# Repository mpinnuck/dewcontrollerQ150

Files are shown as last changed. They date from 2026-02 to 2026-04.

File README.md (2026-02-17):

# Q150 Dew Controller

An intelligent dew prevention system for astronomical telescopes and optical equipment, featuring automatic humidity monitoring and adaptive heating control.

## Overview

The Q150 Dew Controller uses precise temperature and humidity sensing to calculate dew point and automatically control heater power to prevent condensation on telescope optics. The system features both WiFi web interface and Bluetooth Low Energy (BLE) connectivity for remote monitoring and configuration.

## Key Features

### Environmental Monitoring
- **SHT45 Sensor**: High-precision temperature (±0.1°C) and humidity (±1.5% RH) measurement
- **Real-time Dew Point Calculation**: Continuous monitoring of dew point temperature
- **Spread Tracking**: Calculates temperature margin above dew point

### Intelligent Heating Control
- **Adaptive Power Control**: Automatically adjusts heater power based on dew point spread
- **Configurable Power Table**: Up to 5 spread→power mapping points for custom response curves
- **Manual Override**: Direct power control via slider (0-100%)
- **PWM Output**: Smooth, efficient heater control on D8 pin

### Connectivity

#### WiFi Web Interface
- **Responsive Design**: Works on desktop, tablet, and mobile devices
- **Real-time Updates**: Live sensor readings every 2 seconds
- **Configuration**: WiFi credentials, timezone, and heater settings
- **Fast Disconnect Detection**: 1-second timeout for quick offline status
- **Automatic Reconnection**: Seamless recovery when connection is restored

#### Bluetooth Low Energy (BLE)
- **Desktop Management App**: Python-based configuration tool
- **Auto-connect**: Automatically finds and connects to Q150 devices
- **Config Management**: Read/write heater settings and spread table
- **Cross-platform**: macOS, Windows, Linux support

### Time & Logging
- **NTP Time Sync**: Automatic time synchronization via internet
- **Timezone Support**: 18 worldwide timezones with automatic DST adjustment
- **POSIX Timezones**: Full support for complex timezone rules
- **Timestamped Logs**: Real date/time stamps when NTP synced, boot time otherwise

### Network Modes
- **Station Mode**: Connects to existing WiFi network
- **Fallback AP Mode**: Creates "Q150Dew" access point if connection fails
- **mDNS**: Access via `q150dew.local` hostname
- **Persistent Settings**: WiFi credentials stored in flash

## Hardware

### Microcontroller
- **Board**: Seeed Studio XIAO ESP32-S3
- **CPU**: Dual-core Xtensa 32-bit LX7 @ 240MHz
- **Memory**: 512KB SRAM, 8MB Flash
- **Connectivity**: WiFi 802.11 b/g/n, BLE 5.0

### Sensor
- **Model**: Sensirion SHT45
- **Interface**: I2C (SDA=D4, SCL=D5)
- **Accuracy**: ±0.1°C, ±1.5% RH
- **Range**: -40°C to 125°C, 0-100% RH

### Output
- **PWM Pin**: D8 (Pin 9)
- **Frequency**: 1 kHz
- **Resolution**: 8-bit (0-255)
- **Driver**: External MOSFET (FQP30N06) for high-current loads

### PCB
- Custom KiCAD design in `hardware/dewcontrollerQ150/`
- Gerber files ready for fabrication in `hardware/dewcontrollerQ150/pcbfiles/`

### Enclosure
- FreeCAD design in `housing/Q150DewController.FCStd`
- STL files for 3D printing in `housing/stl/`

## Firmware

**Version**: 2.1  
**File**: `firmware/dewcontrollerq150/dewcontrollerq150.ino`

### Dependencies
Install via Arduino Library Manager:
- ArduinoJson (6.x)
- Adafruit SHT4x Library
- ESP32 BLE Arduino

### Compilation
1. Install [Arduino IDE](https://www.arduino.cc/en/software) or [PlatformIO](https://platformio.org/)
2. Install ESP32 board support: https://docs.espressif.com/projects/arduino-esp32/
3. Select board: **XIAO_ESP32S3**
4. Open `firmware/dewcontrollerq150/dewcontrollerq150.ino`
5. Set `DEBUG` to `0` for release build (line 16)
6. Compile and upload

### Configuration
Default WiFi fallback credentials:
- **SSID**: `Q150Dew`
- **Password**: `tinka`

Default timezone: Australia (Sydney/Melbourne) with automatic DST

## Desktop Application

**File**: `app/q150dewcontroller.py`

### Features
- Auto-discovery and connection to Q150 devices
- Read device info and current configuration
- Edit and update:
  - Heater enable/disable
  - Spread→Power table (5 entries)
  - WiFi SSID and password
  - Timezone selection
- Real-time status monitoring
- Cross-platform (macOS, Windows, Linux)

### Requirements
```bash
pip install bleak
```

### Running
```bash
cd app
python q150dewcontroller.py
```

### Building Executable
```bash
cd app
pyinstaller q150dewcontroller.spec --noconfirm
```

Built app will be in `app/dist/q150dewcontroller.app` (macOS) or `app/dist/q150dewcontroller.exe` (Windows)

## Usage

### Initial Setup
1. Power on the Q150 Dew Controller
2. Connect to WiFi AP "Q150Dew" (password: "tinka")
3. Open browser to `http://192.168.4.1` or `http://q150dew.local`
4. Configure your WiFi credentials and timezone
5. Device will restart and connect to your network

### Web Interface
Access via `http://q150dew.local` or device IP address

**Main Panel**:
- Temperature, humidity, dew point, and spread readings
- Heater status (ON/OFF) and current power level
- WiFi connection status and signal strength
- Current time (when NTP synced)

**Control Panel**:
- **Toggle Heater**: Enable/disable automatic control
- **Manual Power Slider**: Override automatic control (0-100%)
- **Spread Table**: Configure up to 5 spread→power points
- **WiFi Config**: Update credentials and timezone

**System Log**:
- Real-time event log with timestamps
- Pause/resume log updates
- Connection status, sensor readings, configuration changes

### BLE Management App
1. Launch `q150dewcontroller` application
2. Click **Scan & Connect** to find devices
3. Device info and status display automatically
4. Edit configuration settings as needed
5. Click **Write Config** to save changes to device

### Power Table Configuration
Define the relationship between temperature spread (T - Tdew) and heater power:

Example table:
| Spread (°C) | Power (%) |
|---|---|
| 0.0 | 100 |
| 2.0 | 75 |
| 5.0 | 50 |
| 10.0 | 25 |
| 15.0 | 0 |

The controller interpolates between points for smooth power transitions.

## Technical Details

### API Endpoints

**GET /api/status**
Returns current sensor readings, heater status, WiFi info, and time

**POST /api/toggle**
Toggles heater enabled state

**POST /api/power**
Sets manual power override (0-100)

**POST /api/config**
Updates heater configuration and spread table

**POST /api/wifi**
Updates WiFi credentials and timezone (triggers restart)

**GET /api/log**
Returns system event log

### BLE Characteristics

**Service UUID**: `12345678-1234-1234-1234-123456789abc`

- **INFO**: Device information (read-only)
- **STATUS**: Real-time sensor data (read/notify)
- **CONFIG**: Configuration settings (read/write)
- **CMD**: Command interface (write)

### Dew Point Calculation
Uses Magnus formula:
```
γ(T,RH) = ln(RH/100) + (b×T)/(c+T)
Tdew = (c×γ)/(b-γ)
```
Where: b = 17.62, c = 243.12°C

### Timezone Support
18 timezones with POSIX format including:
- UTC, UK (GMT/BST)
- Europe (CET, EET)
- US (EST, CST, MST, PST, AKST, HST)
- Australia (AEST, ACST, AWST)
- New Zealand, Japan, China, India, Middle East

Automatic daylight saving time adjustments.

## Development

### Repository Structure
```
dewcontrollerQ150/
├── firmware/
│   └── dewcontrollerq150/
│       └── dewcontrollerq150.ino    # ESP32 firmware
├── app/
│   ├── q150dewcontroller.py         # Python BLE app
│   └── q150dewcontroller.spec       # PyInstaller spec
├── hardware/
│   └── dewcontrollerQ150/
│       ├── dewcontrollerQ150.kicad_pcb   # PCB design
│       ├── dewcontrollerQ150.kicad_sch   # Schematic
│       └── pcbfiles/                     # Gerber files
└── housing/
    ├── Q150DewController.FCStd      # FreeCAD model
    └── stl/                         # 3D print files
```

### Version History
- **v2.1**: Debounced slider, improved disconnect detection, timezone config in BLE app
- **v2.0**: WiFi configuration, NTP time sync, responsive mobile UI
- **v1.3**: Enhanced BLE, power table configuration
- **v1.2**: PCB revision, housing design
- **v1.0**: Initial production version

## Troubleshooting

**Device won't connect to WiFi**
- Check SSID and password in WiFi Config
- Ensure 2.4GHz WiFi (5GHz not supported)
- Device will fall back to AP mode "Q150Dew" if connection fails

**Web interface shows "Disconnected"**
- Check device is powered on
- Verify you're on the same network
- Try accessing by IP address instead of hostname

**NTP time not syncing**
- Requires internet connection
- Check timezone setting is correct
- Time will show "Not synced" until successful NTP update

**Heater not responding**
- Check heater is enabled (not just power set)
- Verify MOSFET and heater connections
- Check spread table has valid entries

## License

Copyright © 2026 Mark Pinnuck

## Acknowledgments

- Sensirion for SHT45 sensor library
- Seeed Studio for XIAO ESP32-S3 platform
- Arduino and ESP32 communities

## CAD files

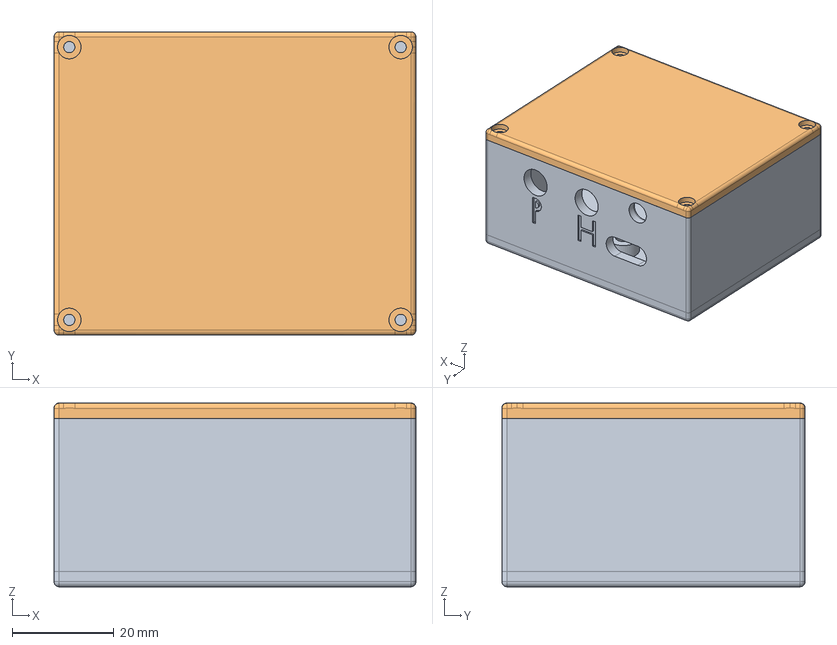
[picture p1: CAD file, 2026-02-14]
housing/Q150DewController.FCStd
71.0 x 59.5 x 36.0 mm
Base
Lid

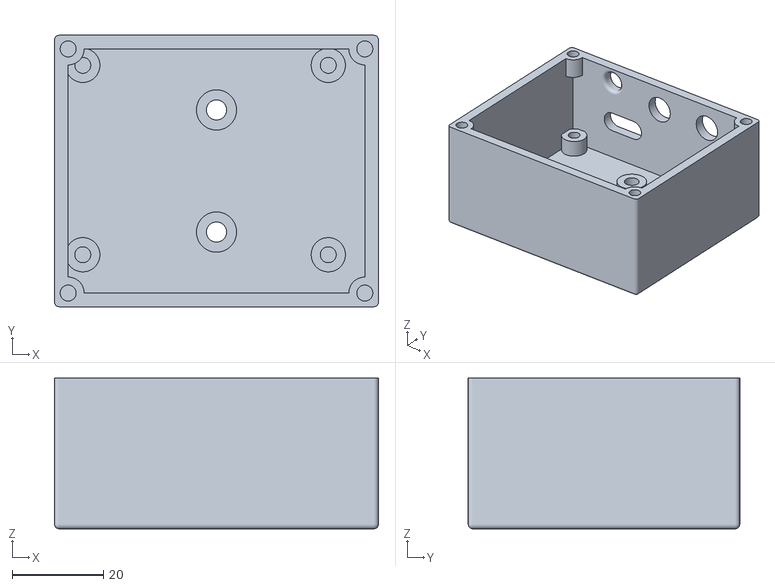
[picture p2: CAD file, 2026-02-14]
housing/stl/Base.stl
71.0 x 59.5 x 33.0

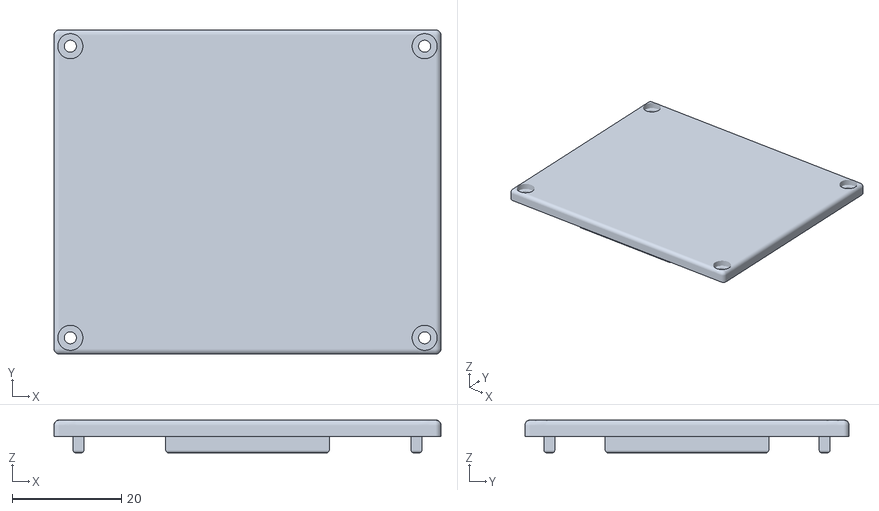
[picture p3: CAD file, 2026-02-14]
housing/stl/Lid.stl
71.0 x 59.5 x 6.00

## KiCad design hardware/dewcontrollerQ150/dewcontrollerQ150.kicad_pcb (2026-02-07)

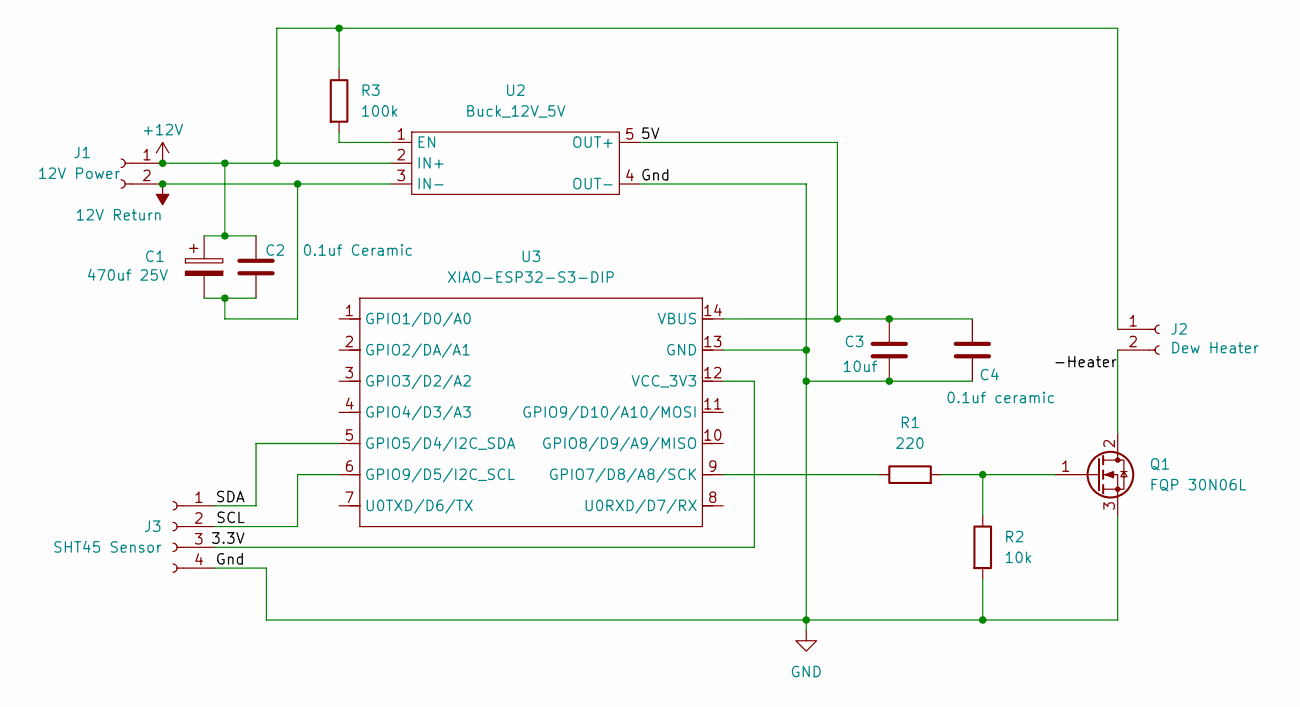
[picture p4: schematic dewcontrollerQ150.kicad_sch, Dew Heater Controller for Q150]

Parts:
C1: 470uf 25V; CP_Radial_D10.0mm_P5.00mm
C2: 0.1uf Ceramic; C_Disc_D5.1mm_W3.2mm_P5.00mm
C3: 10uf; C_Disc_D5.1mm_W3.2mm_P5.00mm
C4: 0.1uf ceramic; C_Disc_D5.1mm_W3.2mm_P5.00mm
J1: 12V Power; JST_XH_B2B-XH-A_1x02_P2.50mm_Vertical
J2: Dew Heater; JST_XH_B2B-XH-A_1x02_P2.50mm_Vertical
J3: SHT45 Sensor; JST_XH_B4B-XH-A_1x04_P2.50mm_Vertical
Q1: FQP 30N06L; TO-220-3_Vertical
R1: 220; R_Axial_DIN0207_L6.3mm_D2.5mm_P7.62mm_Horizontal
R2: 10k; R_Axial_DIN0207_L6.3mm_D2.5mm_P7.62mm_Horizontal
R3: 100k; R_Axial_DIN0207_L6.3mm_D2.5mm_P7.62mm_Horizontal
U2: Buck_12V_5V; MP_Buck_Tunghey_5Pin_THT
U3: XIAO-ESP32-S3-DIP; XIAO-ESP32S3-DIP

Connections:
12V Return: C1.2, C2.2, J1.2, U2.3 (IN-)
+12V: C1.1, C2.1, J1.1, J2.1, R3.1, U2.2 (IN+)
/3.3V: J3.3, U3.12 (VCC_3V3)
/5V: C3.1, C4.1, U2.5 (OUT+), U3.14 (VBUS)
/-Heater: J2.2, Q1.2 (D)
/SCL: J3.2, U3.6 (GPIO9/D5/I2C_SCL)
/SDA: J3.1, U3.5 (GPIO5/D4/I2C_SDA)
GND: C3.2, C4.2, J3.4, Q1.3 (S), R2.2, U2.4 (OUT-), U3.13 (GND)
unnamed: Q1.1 (G), R1.2, R2.1
unnamed: R3.2, U2.1 (EN)
unnamed: R1.1, U3.9 (GPIO7/D8/A8/SCK)

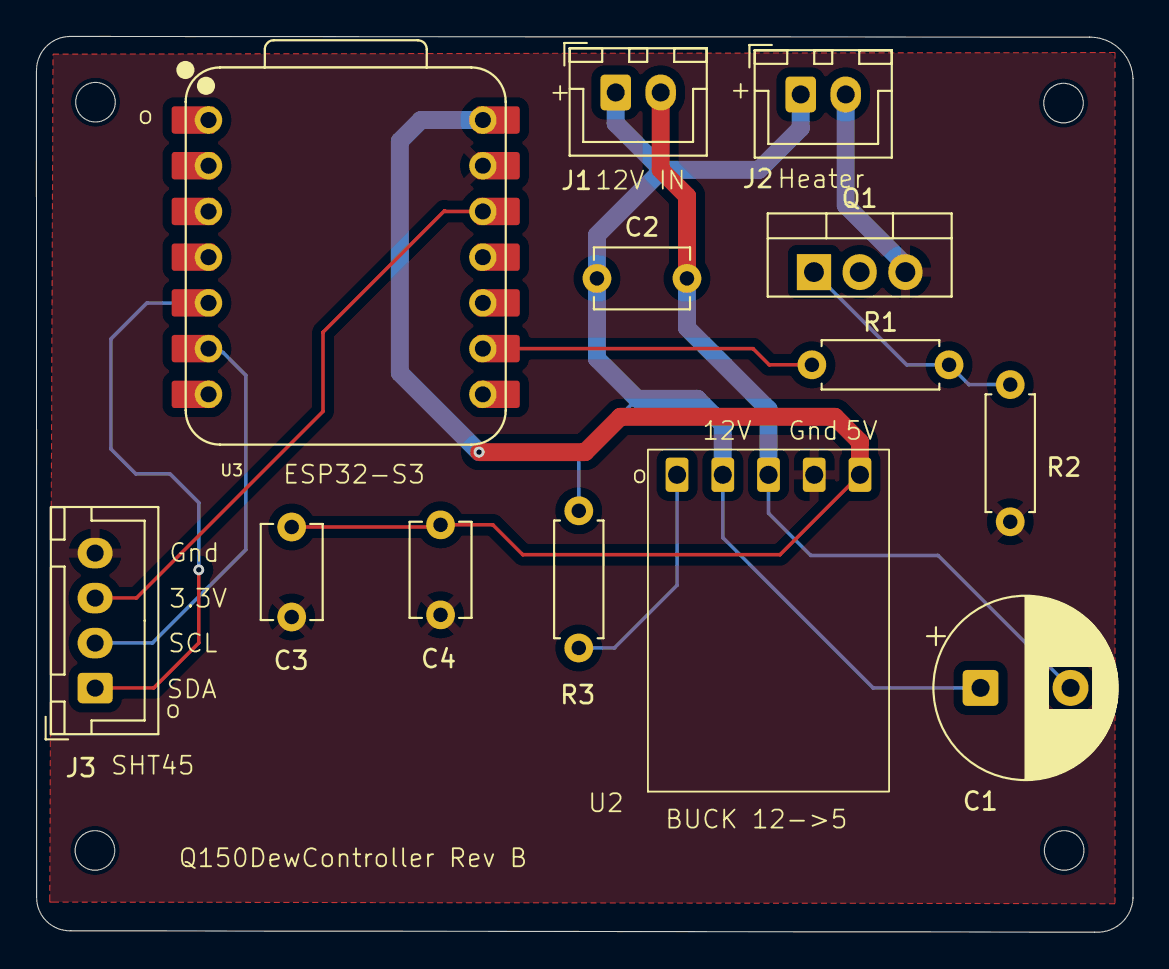
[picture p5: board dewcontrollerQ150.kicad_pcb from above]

Board: 2 copper layers, 60.9 x 49.8 mm, 17 parts (0 on the bottom side), 11 nets.

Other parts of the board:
mh1, mh2, mh3, mh4: MountingHole_2.2mm_M2

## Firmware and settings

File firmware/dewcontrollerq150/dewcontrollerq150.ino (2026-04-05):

/***********************************************************************
 Q150 Dew Controller
 Board : Seeed XIAO ESP32S3
 Control: BLE + WiFi Web Interface
 Sensor : SHT45 (I2C)
 PWM    : D8 (Pin 9, Digital IO D8)
 I2C    : SDA=D4 (Pin 5), SCL=D5 (Pin 6)

 WiFi: Stored in config, falls back to AP mode if no credentials or connection fails
 Fallback AP SSID "Q150Dew", Password "tinka"

 ************************************************************************/

#define FIRMWARE_VERSION "4.2"
#define DEBUG 0   // <<<<<<<<<< SET TO 0 FOR RELEASE BUILD

// =====================================================================
// ========================== DEBUG MACROS ===============================
// =====================================================================
#if DEBUG
  #define DEBUG_BEGIN(x)   Serial.begin(x)
  #define DEBUG_PRINT(x)   Serial.print(x)
  #define DEBUG_PRINTLN(x) Serial.println(x)
#else
  #define DEBUG_BEGIN(x)
  #define DEBUG_PRINT(x)
  #define DEBUG_PRINTLN(x)
#endif

#include <Arduino.h>
#include <Wire.h>
#include <ArduinoJson.h>
#include <Preferences.h>
#include <BLEDevice.h>
#include <BLEServer.h>
#include <BLEUtils.h>
#include <BLE2902.h>
#include <Adafruit_SHT4x.h>
#include <WiFi.h>
#include <WebServer.h>
#include <ESPmDNS.h>
#include <time.h>

// =====================================================================
// =========================== WIFI =====================================
// =====================================================================
// Fallback AP credentials (used when no WiFi configured or connection fails)
const char* FALLBACK_AP_SSID = "Q150Dew";
const char* FALLBACK_AP_PASSWORD = "tinka";

// NTP Configuration
const char* NTP_SERVER1 = "pool.ntp.org";
const char* NTP_SERVER2 = "time.nist.gov";
bool ntpSynced = false;

WebServer server(80);
bool wifiConnected = false;
String wifiStatus = "Disconnected";
int wifiRSSI = 0;
unsigned long lastWiFiCheck = 0;
const unsigned long WIFI_RECONNECT_INTERVAL = 30000; // 30 seconds

// Stored WiFi credentials
String stored_ssid = "";
String stored_password = "";

// =====================================================================
// =========================== HARDWARE =================================
// =====================================================================
#define HEATER_PWM_PIN D8           // Pin 9, Digital IO D8 on XIAO ESP32S3
#define I2C_SDA D4                   // Pin 5, Digital IO D4
#define I2C_SCL D5                   // Pin 6, Digital IO D5
#define LED_PIN LED_BUILTIN          // Built-in LED for status indication

static constexpr int PWM_FREQ_HZ   = 1000;
static constexpr int PWM_RES_BITS  = 10;
static constexpr int PWM_MAX       = (1 << PWM_RES_BITS) - 1;

// Timing intervals (milliseconds)
static constexpr unsigned long SENSOR_READ_INTERVAL_MS = 5000;   // 5 seconds
static constexpr unsigned long STATUS_NOTIFY_INTERVAL_MS = 2000; // 2 seconds
static constexpr unsigned long WIFI_STATUS_CHECK_MS = 5000;      // 5 seconds

// =====================================================================
// =========================== SENSOR ===================================
// =====================================================================
static Adafruit_SHT4x sht4 = Adafruit_SHT4x();

// =====================================================================
// =========================== DEW MATH =================================
// =====================================================================
static float dewPointC(float T, float RH) {
  if (isnan(T) || isnan(RH) || RH <= 0.0f) return NAN;
  const float a = 17.62f;
  const float b = 243.12f;
  float g = (a * T) / (b + T) + logf(RH / 100.0f);
  return (b * g) / (a - g);
}

// =====================================================================
// ===================== SPREAD → POWER TABLE ============================
// =====================================================================
static constexpr int MAX_TABLE = 5;

struct SpreadPowerEntry {
  float   spreadC;
  uint8_t powerPct;
};

struct Config {
  uint8_t cfgVersion = 1;
  bool heaterEnabled = false;
  uint8_t count = 3;
  char wifiSSID[32] = "";        // Store WiFi SSID
  char wifiPassword[64] = "";    // Store WiFi Password
  char timezone[64] = "AEST-10AEDT,M10.1.0,M4.1.0/3";     // POSIX timezone string (handles DST automatically)

  SpreadPowerEntry table[MAX_TABLE] = {
    {5.0f, 8},
    {3.0f, 15},
    {2.0f, 22},
    {1.0f, 30},
    {0.5f, 40}
  };
};

static Config g_cfg;
static Preferences g_prefs;

// Forward declarations
static void sortTableDescending(Config& cfg);
static uint8_t powerFromSpread(const Config& cfg, float spreadC);

// =====================================================================
// =========================== STATE ====================================
// =====================================================================
static float g_T = NAN;
static float g_RH = NAN;
static float g_Td = NAN;
static float g_spread = NAN;
static uint8_t g_powerPct = 0;
static bool g_manual_mode = false;   // manual power override mode
static uint8_t g_manual_power = 0;   // manual power value (0-100)

// Log buffer for web interface
String logBuffer = "";
const int MAX_LOG_SIZE = 16384;  // 16KB log buffer

// =====================================================================
// ============================= BLE ====================================
// =====================================================================
static const char* BLE_DEVICE_NAME = "Q150DewController";

#define SVC_UUID    "ab120000-0000-0000-0000-000000000001"
#define STATUS_UUID "ab120000-0000-0000-0000-000000000002"
#define CONFIG_UUID "ab120000-0000-0000-0000-00000000C003"
#define INFO_UUID   "ab120000-0000-0000-0000-000000000004"
#define CMD_UUID    "ab120000-0000-0000-0000-000000000005"

static BLEServer* g_server = nullptr;
static BLECharacteristic* g_statusChar = nullptr;
static BLECharacteristic* g_configChar = nullptr;
static BLECharacteristic* g_infoChar = nullptr;
static BLECharacteristic* g_cmdChar = nullptr;

// BLE pending operations (flags + buffers)
static constexpr size_t CONFIG_BUFFER_SIZE = 512;
static constexpr size_t CMD_BUFFER_SIZE = 64;

static volatile bool g_configWritePending = false;
static char g_configWriteBuffer[CONFIG_BUFFER_SIZE];
static volatile bool g_cmdWritePending = false;
static char g_cmdWriteBuffer[CMD_BUFFER_SIZE];
static portMUX_TYPE g_bleMux = portMUX_INITIALIZER_UNLOCKED;

// =====================================================================
// ======================== BLE CALLBACKS ===============================
// =====================================================================
class ServerCallbacks : public BLEServerCallbacks {
public:
  void onConnect(BLEServer* pServer) {
    DEBUG_PRINTLN(F("✅ BLE CLIENT CONNECTED"));
    addLog("BLE client connected");
  }
  
  void onDisconnect(BLEServer* pServer) {
    DEBUG_PRINTLN(F("❌ BLE disconnected — restarting advertising"));
    addLog("BLE client disconnected");
    BLEDevice::startAdvertising();
  }
};

class ConfigCallbacks : public BLECharacteristicCallbacks {
  void onRead(BLECharacteristic* pCharacteristic) {
    // Minimal - value is pre-set in loop()
  }
  
  void onWrite(BLECharacteristic* pCharacteristic) {
    DEBUG_PRINTLN(F("📝 CONFIG callback triggered"));
    // Capture and flag with critical section to prevent reordering
    String value = pCharacteristic->getValue();
    size_t len = min(value.length(), CONFIG_BUFFER_SIZE - 1);
    portENTER_CRITICAL(&g_bleMux);
    memcpy(g_configWriteBuffer, value.c_str(), len);
    g_configWriteBuffer[len] = '\0';
    g_configWritePending = true;
    portEXIT_CRITICAL(&g_bleMux);
    DEBUG_PRINTLN(F("📝 CONFIG callback complete"));
  }
};

class CmdCallbacks : public BLECharacteristicCallbacks {
  void onWrite(BLECharacteristic* pCharacteristic) {
    DEBUG_PRINTLN(F("🎮 CMD callback triggered"));
    // Capture and flag with critical section to prevent reordering
    String value = pCharacteristic->getValue();
    size_t len = min(value.length(), CMD_BUFFER_SIZE - 1);
    portENTER_CRITICAL(&g_bleMux);
    memcpy(g_cmdWriteBuffer, value.c_str(), len);
    g_cmdWriteBuffer[len] = '\0';
    g_cmdWritePending = true;
    portEXIT_CRITICAL(&g_bleMux);
    DEBUG_PRINTLN(F("🎮 CMD callback complete"));
  }
};

// Create static callback instances
static ServerCallbacks serverCallbacks;
static ConfigCallbacks configCallbacks;
static CmdCallbacks cmdCallbacks;

// =====================================================================
// ========================== NTP SETUP =================================
// =====================================================================
void setupNTP() {
  if (!wifiConnected) {
    addLog("⚠️ Cannot setup NTP - not connected to WiFi");
    return;
  }

  addLog("🕐 Configuring NTP with timezone: " + String(g_cfg.timezone));
  configTime(0, 0, NTP_SERVER1, NTP_SERVER2);
  setenv("TZ", g_cfg.timezone, 1);
  tzset();

  // Wait up to 5 seconds for time sync
  int attempts = 0;
  struct tm timeinfo;
  while (!getLocalTime(&timeinfo) && attempts < 10) {
    delay(500);
    attempts++;
  }

  if (getLocalTime(&timeinfo)) {
    ntpSynced = true;
    char timeStr[64];
    strftime(timeStr, sizeof(timeStr), "%Y-%m-%d %H:%M:%S", &timeinfo);
    addLog("✅ NTP synced: " + String(timeStr));
  } else {
    ntpSynced = false;
    addLog("❌ NTP sync failed - time not available");
  }
}

String getCurrentTime() {
  if (!ntpSynced) return "--";
  
  struct tm timeinfo;
  if (!getLocalTime(&timeinfo)) {
    return "--";
  }
  
  char timeStr[64];
  strftime(timeStr, sizeof(timeStr), "%Y-%m-%d %H:%M:%S", &timeinfo);
  return String(timeStr);
}

// =====================================================================
// =========================== LOGGING ==================================
// =====================================================================
void addLog(const String& msg) {
  String timestamp;
  
  if (ntpSynced) {
    // Use real date-time when NTP is synced
    struct tm timeinfo;
    if (getLocalTime(&timeinfo)) {
      char timeStr[32];
      strftime(timeStr, sizeof(timeStr), "%Y-%m-%d %H:%M:%S", &timeinfo);
      timestamp = String(timeStr);
    } else {
      // Fallback to seconds if getLocalTime fails
      unsigned long ms = millis();
      timestamp = String(ms / 1000) + "s";
    }
  } else {
    // Use seconds since boot when NTP not synced
    unsigned long ms = millis();
    timestamp = String(ms / 1000) + "s";
  }
  
  String logLine = "[" + timestamp + "] " + msg;
  DEBUG_PRINTLN(logLine);
  
  logBuffer += logLine + "\n";
  if (logBuffer.length() > MAX_LOG_SIZE) {
    logBuffer = logBuffer.substring(logBuffer.length() - MAX_LOG_SIZE);
  }
}

// =====================================================================
// =========================== WIFI SETUP ===============================
// =====================================================================
void setupWiFi() {
  pinMode(LED_PIN, OUTPUT);
  digitalWrite(LED_PIN, LOW);

  // Check if we have stored credentials
  ///*
  if (strlen(g_cfg.wifiSSID) == 0) {
    addLog("⚠️ No WiFi credentials configured - starting in AP mode");
    WiFi.mode(WIFI_AP);
    WiFi.softAP(FALLBACK_AP_SSID, FALLBACK_AP_PASSWORD);
    IPAddress apIP = WiFi.softAPIP();
    addLog("📡 AP mode started — connect to SSID '" + String(FALLBACK_AP_SSID) + "'");
    addLog("📶 AP IP address: " + apIP.toString());
    setupWebServer();
    return;
  }
  //*/
  stored_ssid = String(g_cfg.wifiSSID);
  stored_password = String(g_cfg.wifiPassword);
//  stored_ssid = String("AstroNet-2G");
//  stored_password = String("leanneannatinka");
  addLog("🔌 Connecting to Wi-Fi: " + stored_ssid);

  // --- Step 1: Clean disconnect and setup STA mode ---
  WiFi.disconnect(true, true);
  delay(200);
  WiFi.persistent(false);
  WiFi.mode(WIFI_STA);
  WiFi.setSleep(false);
  WiFi.setAutoReconnect(true);
  WiFi.setTxPower(WIFI_POWER_19_5dBm);  // Stronger signal for tough connections

  // --- Step 2: Set hostname ---
  WiFi.setHostname("Q150Dew");

  // --- Step 3: Begin initial connection ---
  WiFi.begin(stored_ssid.c_str(), stored_password.c_str());
  delay(500); // short warm-up

  const int maxRetries = 60;  // total loop time ≈ 60s (increased for slow extender)
  int retries = 0;
  wl_status_t lastStatus = WL_IDLE_STATUS;

  // --- Step 4: Poll connection progress safely ---
  addLog("⏳ Waiting for Wi-Fi connection (can take up to 45s in extender mode)...");
  while (WiFi.status() != WL_CONNECTED && retries < maxRetries) {
    wl_status_t status = WiFi.status();

    // Log only when status changes
    if (status != lastStatus) {
      String statusMsg;
      switch (status) {
        case WL_IDLE_STATUS:      statusMsg = "Idle"; break;
        case WL_NO_SSID_AVAIL:    statusMsg = "No SSID available"; break;
        case WL_SCAN_COMPLETED:   statusMsg = "Scan completed"; break;
        case WL_CONNECTED:        statusMsg = "Connected"; break;
        case WL_CONNECT_FAILED:   statusMsg = "Connect failed"; break;
        case WL_CONNECTION_LOST:  statusMsg = "Connection lost"; break;
        case WL_DISCONNECTED:     statusMsg = "Disconnected"; break;
        default:                  statusMsg = "Unknown (" + String(status) + ")"; break;
      }
      addLog("⏳ Wi-Fi status: " + statusMsg);
      lastStatus = status;
    }

    delay(1000);
    retries++;
  }

  // --- Step 5: Handle success immediately ---
  if (WiFi.status() == WL_CONNECTED) {
    digitalWrite(LED_PIN, HIGH);
    wifiConnected = true;
    wifiStatus = "Connected to " + stored_ssid;
    wifiRSSI = WiFi.RSSI();
    addLog("✅ Wi-Fi connected");
    addLog("🌐 IP address: " + WiFi.localIP().toString());
    addLog("📶 RSSI: " + String(wifiRSSI) + " dBm");

    if (!MDNS.begin("q150dew")) {
      addLog("❌ mDNS failed to start!");
    } else {
      addLog("✅ mDNS responder started as q150dew.local");
    }

    setupNTP();
    setupWebServer();
    return;
  }

  // --- Step 6: Grace period for late DHCP (important for slow extender) ---
  addLog("⚠️ Connection not confirmed after " + String(maxRetries) + " attempts.");
  addLog("⏱ Waiting up to 15 more seconds for late DHCP...");

  unsigned long graceStart = millis();
  bool connected = false;
  while (millis() - graceStart < 15000) {
    if (WiFi.status() == WL_CONNECTED) {
      connected = true;
      break;
    }
    delay(1000);
  }

  if (connected) {
    digitalWrite(LED_PIN, HIGH);
    wifiConnected = true;
    wifiStatus = "Connected to " + stored_ssid;
    wifiRSSI = WiFi.RSSI();
    addLog("✅ Late Wi-Fi success detected!");
    addLog("🌐 IP address: " + WiFi.localIP().toString());
    addLog("📶 RSSI: " + String(wifiRSSI) + " dBm");

    if (!MDNS.begin("q150dew")) {
      addLog("❌ mDNS failed to start!");
    } else {
      addLog("✅ mDNS responder started as q150dew.local");
    }

    setupNTP();
    setupWebServer();
    return;
  }

  // --- Step 7: Fallback to AP mode ---
  addLog("❌ Wi-Fi connection failed after extended wait. Switching to Access Point mode...");
  wifiConnected = false;
  wifiStatus = "AP Mode: " + String(FALLBACK_AP_SSID);
  WiFi.mode(WIFI_AP);
  WiFi.softAP(FALLBACK_AP_SSID, FALLBACK_AP_PASSWORD);
  IPAddress apIP = WiFi.softAPIP();
  addLog("📡 AP mode started — connect to SSID '" + String(FALLBACK_AP_SSID) + "'");
  addLog("📶 AP IP address: " + apIP.toString());
  setupWebServer();
}

// =====================================================================
// ===================== WIFI STATUS CHECK ==============================
// =====================================================================
void checkWiFiStatus() {
  static unsigned long lastReconnectAttempt = 0;
  static unsigned long offlineSince = 0;
  static bool wasDisconnected = false;
  static unsigned long lastConnectionCheck = 0;
  static unsigned long lastScanCheck = 0;
  static bool scanning = false;

  // If we're in AP mode, periodically check if our configured network is available
  if (WiFi.getMode() == WIFI_AP) {
    wifiStatus = "AP Mode: " + String(FALLBACK_AP_SSID);
    wifiRSSI = 0; // No meaningful RSSI in AP mode
    
    // Only try to scan if we have credentials
    if (strlen(g_cfg.wifiSSID) > 0) {
      unsigned long now = millis();
      
      // Scan for networks every 30 seconds when in AP mode
      if (now - lastScanCheck > 30000 && !scanning) {
        lastScanCheck = now;
        scanning = true;
        addLog("📡 AP mode: Scanning for configured network...");
        
        // Start scan in non-blocking mode
        WiFi.scanNetworks(true);
      }
      
      // Check if scan is complete
      if (scanning) {
        int scanResult = WiFi.scanComplete();
        if (scanResult >= 0) {
          // Scan complete
          scanning = false;
          
          // Check if our SSID is in the list
          for (int i = 0; i < scanResult; i++) {
            String foundSSID = WiFi.SSID(i);
            if (foundSSID.equals(String(g_cfg.wifiSSID))) {
              addLog("✅ Found configured network: " + foundSSID + " - attempting connection...");
              
              // Stop AP mode and try to connect
              WiFi.softAPdisconnect(true);
              WiFi.mode(WIFI_STA);
              WiFi.begin(g_cfg.wifiSSID, g_cfg.wifiPassword);
              break;
            }
          }
          WiFi.scanDelete();
        } else if (scanResult == -1) {
          // Scan still in progress
          return;
        } else if (scanResult == -2) {
          // Scan not triggered or failed
          scanning = false;
        }
      }
    }
    return;
  }

  // Force a connection check every second
  if (millis() - lastConnectionCheck > 1000) {
    lastConnectionCheck = millis();
    
    // Check if we're actually connected by sending a probe
    if (WiFi.status() == WL_CONNECTED) {
      // Even if WiFi.status says connected, verify we can reach the AP
      // by checking RSSI - if it's -127, we're not really connected
      int rssi = WiFi.RSSI();
      if (rssi == -127) {
        // Force disconnection
        addLog("⚠️ False connection detected (RSSI=" + String(rssi) + "), forcing reconnect");
        WiFi.disconnect();
        return;
      }
    }
  }

  // No credentials? Shouldn't be in STA mode, but just in case
  if (strlen(g_cfg.wifiSSID) == 0) {
    return;
  }

  wl_status_t status = WiFi.status();

  // ---- Case 1: STA is connected ----
  if (status == WL_CONNECTED) {
    if (wasDisconnected) {
      wasDisconnected = false;
      offlineSince = 0;

      wifiConnected = true;
      wifiStatus = "Connected to " + stored_ssid;
      wifiRSSI = WiFi.RSSI();
      addLog("✅ Wi-Fi reconnected: " + WiFi.localIP().toString());

      delay(500); // give stack time to stabilise

      if (!MDNS.begin("q150dew")) {
        addLog("❌ Failed to restart mDNS responder!");
      } else {
        addLog("✅ mDNS responder restarted as q150dew.local");
      }

      // Restart web server to bind to new interface
      server.stop();
      delay(200);
      setupNTP();
      setupWebServer();
      addLog("🌐 Web server rebound to Wi-Fi interface");
    }
    
    // Update RSSI even when connected
    wifiRSSI = WiFi.RSSI();
    return;
  }

  // ---- Case 2: Not connected ----
  if (!wasDisconnected) {
    wasDisconnected = true;
    offlineSince = millis();
    wifiConnected = false;
    wifiStatus = "Disconnected";
    addLog("⚠️ Wi-Fi disconnected, will attempt reconnect...");
  }

  unsigned long now = millis();
  const unsigned long reconnectIntervalMs = 10000; // 10 seconds
  if (now - lastReconnectAttempt < reconnectIntervalMs) return;
  lastReconnectAttempt = now;

  // Check current status - don't interrupt if connection is in progress
  if (status == WL_IDLE_STATUS || status == WL_DISCONNECTED) {
    // Connection attempt finished but failed - safe to retry
    addLog("🔁 Retrying WiFi connection...");
    WiFi.begin(g_cfg.wifiSSID, g_cfg.wifiPassword);
  }
  else if (status == WL_NO_SSID_AVAIL || status == WL_CONNECT_FAILED) {
    // Hard failure states - only after prolonged offline do a full reset
    const unsigned long offlineResetMs = 90000; // 90s
    if (offlineSince && (now - offlineSince > offlineResetMs)) {
      addLog("🧩 WiFi offline for >90s — performing hard reset...");
      WiFi.disconnect(true, true);
      delay(200);
      WiFi.mode(WIFI_STA);
      WiFi.setHostname("Q150Dew");
      WiFi.begin(g_cfg.wifiSSID, g_cfg.wifiPassword);
      offlineSince = now;  // Reset timer after hard reset
    } else {
      // Try again without disrupting the stack
      addLog("🔁 Retrying after connection failure...");
      WiFi.begin(g_cfg.wifiSSID, g_cfg.wifiPassword);
    }
  }
  // else: status is WL_SCAN_COMPLETED or other transient state - let it continue
}
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
void loop() {
  static unsigned long lastRead = 0;
  static unsigned long lastNotify = 0;
  static unsigned long lastConfigUpdate = 0;
  static unsigned long lastWiFiStatusCheck = 0;
  unsigned long now = millis();

  // Process pending BLE operations FIRST (minimal latency)
  processPendingConfigWrite();
  processPendingCmdWrite();

  // Check BLE connection
  bleWatchdog();

  // Handle web server clients
  server.handleClient();

  // Check WiFi status periodically
  if (now - lastWiFiStatusCheck >= WIFI_STATUS_CHECK_MS) {
    lastWiFiStatusCheck = now;
    checkWiFiStatus();
  }

  // LED status indication (handles AP blink, connected solid, disconnected off)
  handleLEDStatus();

  if (now - lastRead >= SENSOR_READ_INTERVAL_MS) {
    lastRead = now;
    updateReadingsAndControl();
  }

  if (now - lastNotify >= STATUS_NOTIFY_INTERVAL_MS && g_statusChar) {
    lastNotify = now;
    String status = encodeStatusJson();
    g_statusChar->setValue(status.c_str());
    g_statusChar->notify();
  }

  delay(10);
}

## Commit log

2026-01-28 v0.1 initial
    [dewcontrollerQ150.kicad_pcb, dewcontrollerQ150.kicad_sch]
2026-01-29 V0.5 switched to ESP32S3
2026-01-29 V0.51 updated KiCAD schematic with S3
    [dewcontrollerQ150.kicad_sch]
2026-01-31 v0.6 tidy up code
    [dewcontrollerQ150.kicad_pcb, dewcontrollerQ150.kicad_sch]
2026-02-02 v0.7 Latest CAD and KiCAD files
    [Base.stl, Lid.stl, Q150DewController.FCStd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]
2026-02-07 V1.2 PCB fixed ESP32S3 and FQP30N06 footprints
    [Base.stl, Q150DewController.FCStd, dewcontrollerQ150.kicad_pcb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]
2026-02-07 v1.2b Changed esp32-S3 to correct footprint
    [dewcontrollerQ150.kicad_pcb, dewcontrollerQ150.kicad_sch]
2026-02-14 v1.2b housing updates
    [Base.stl, Lid.stl, Q150DewController.FCStd]
2026-02-14 V1.2c updated power table in ino
2026-03-16 v3.0 correct spread-to-power lookup logic and load saved config into web UI on page load
    [dewcontrollerq150.ino]
2026-04-05 V4.0 review and bug fixes
    [dewcontrollerq150.ino]
2026-04-05 V4.2 updated heater logic
